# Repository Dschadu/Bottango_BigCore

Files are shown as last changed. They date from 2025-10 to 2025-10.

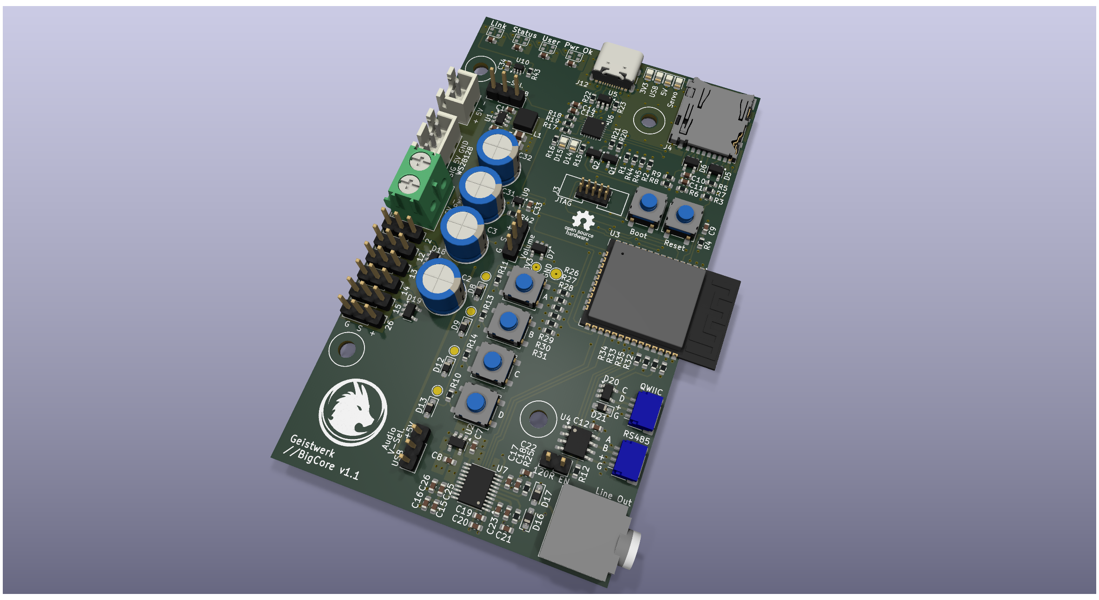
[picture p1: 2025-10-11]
PCB.png

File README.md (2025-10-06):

# ESP32 Bottango Control Board

This custom PCB is designed to serve as a **control and interface board** for projects using the [Bottango](https://www.bottango.com/) motion and animation control firmware.  
It provides robust connectivity, servo control, and expandability for animatronics or motion-based systems.

**Note**: This is a community project and not designed / maintained / officially supported by Bottango.

---

## Features

### Core
- **ESP32 microcontroller**
- **USB-C** connector for power and programming  
- **Selectable power source** for the ESP32:  
  - USB-C  
  - 5 V rail (from WS2812B)

---

### Inputs
- **4 user buttons** — freely assignable, e.g., for selecting animations  
- **1 stop button** — emergency or animation stop  
- **Potentiometer input** — for audio volume control  

---

### Outputs & Indicators
- **4 status LEDs** — indicate board or animation states  
- **Line-out audio output**  
- **6 servo connectors** (powered by dedicated power input)  
- **WS2812B output** — supports addressable RGB LEDs  
- **Selectable power source for audio section:**  
  - USB-C  
  - 5 V rail (from WS2812B)  
- **LED power indicators** for:  
  - 5 V  
  - 6 V  
  - USB-C  
  - 3.3 V  

---

### Connectivity
- **I²C (Qwiic-compatible connector)** — for sensor or peripheral expansion  
- **RS485 interface** — for robust long-distance serial communication  

---

## Power Overview

| Function | Voltage  | Source Options |
|---|---|---|
| ESP32 | 5 V | USB-C / 5 V line |
| Audio Output Circuit | 5 V | USB-C / 5 V line |
| WS2812B LEDs | 5 V | External supply |
| Servos | 6 V | External supply |

---

## Firmware Compatibility

This board is designed for use with **Bottango firmware**, providing smooth integration with Bottango Studio for real-time motion and animation control.  
Learn more at: [https://www.bottango.com/](https://www.bottango.com/)

**Note**: This is a community project and not designed / maintained / officially supported by Bottango.

---

## License

This hardware design is released under the  
**CERN Open Hardware Licence Version 2 – Weakly Reciprocal (CERN-OHL-W)**.  
© 2025 Martin Klein 

You are free to:
- Use, study, modify, and manufacture this design  
- Distribute modified versions under the same license  
- Incorporate this board into larger, closed-source systems, **as long as modifications to this board itself remain open-source**

For more information, see the [LICENSE](./LICENSE) file or the full text at
[CERN-OHL-W](https://gitlab.com/ohwr/project/cernohl/-/wikis/uploads/82b567f43ce515395f7ddbfbad7a8806/cern_ohl_w_v2.txt)

## Copyright Notice

Copyright Martin Klein 2025.

This source describes Open Hardware and is licensed under the CERN-OHLW v2

You may redistribute and modify this PCB and make products
using it under the terms of the CERN-OHL-W v2 (https:/cern.ch/cern-ohl).
This PCB is distributed WITHOUT ANY EXPRESS OR IMPLIED
WARRANTY, INCLUDING OF MERCHANTABILITY, SATISFACTORY QUALITY
AND FITNESS FOR A PARTICULAR PURPOSE. Please see the CERN-OHL-W v2
for applicable conditions.

Source location: https://github.com/Dschadu/Geistwerk-BigCore

As per CERN-OHL-W v2 section 4.1, should You produce hardware based on
these sources, You must maintain the Source Location visible in its
documentation.

## Acknowledgments

Special thanks to the Bottango team for providing an intuitive open platform for animatronic motion control.

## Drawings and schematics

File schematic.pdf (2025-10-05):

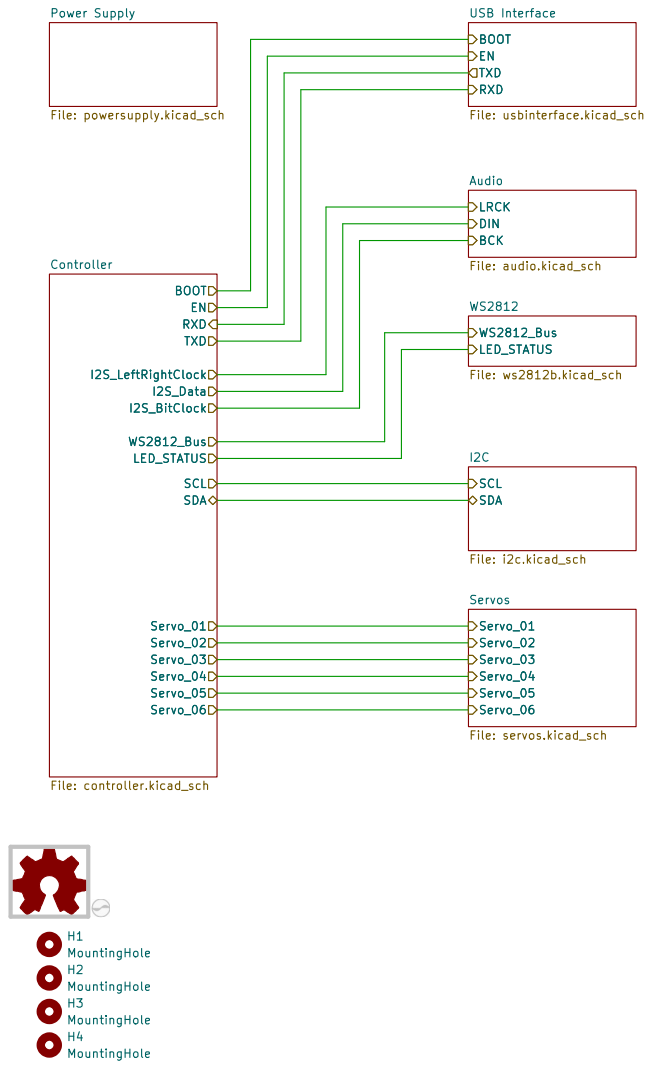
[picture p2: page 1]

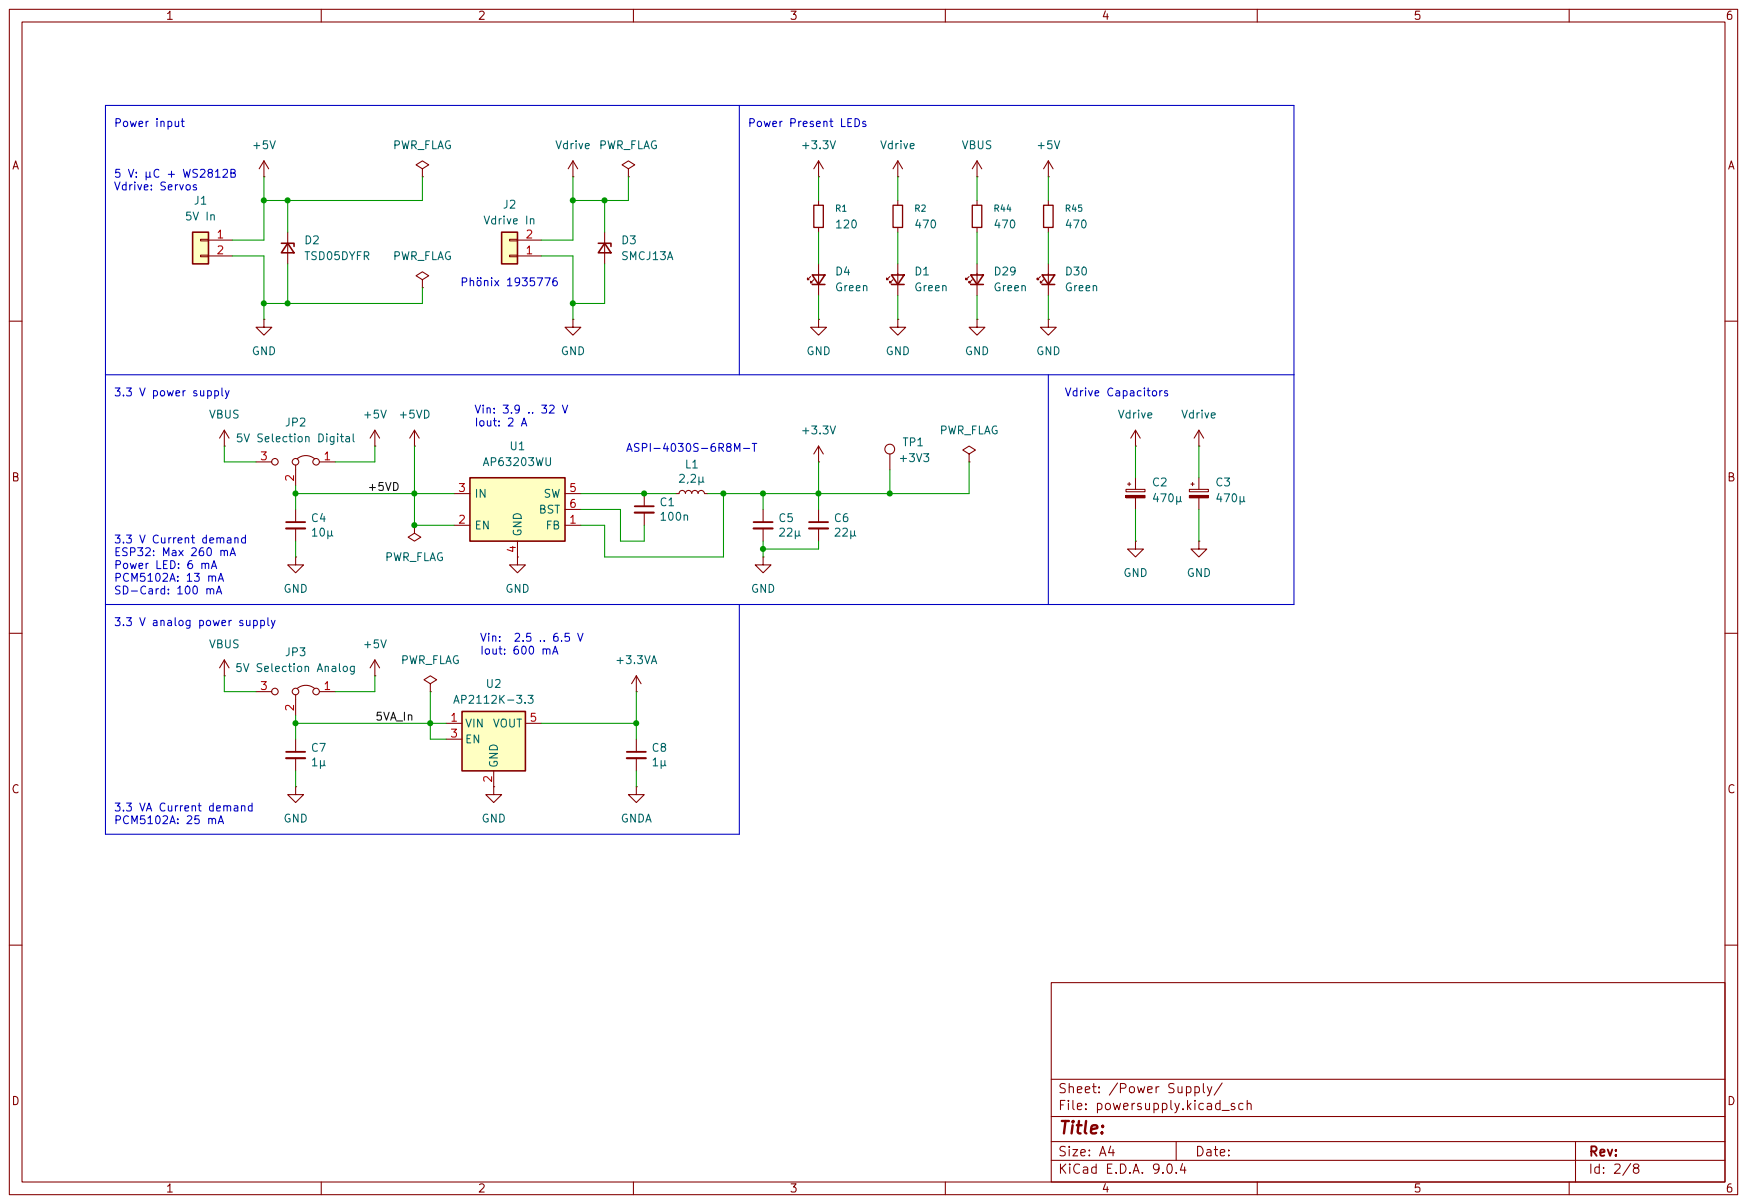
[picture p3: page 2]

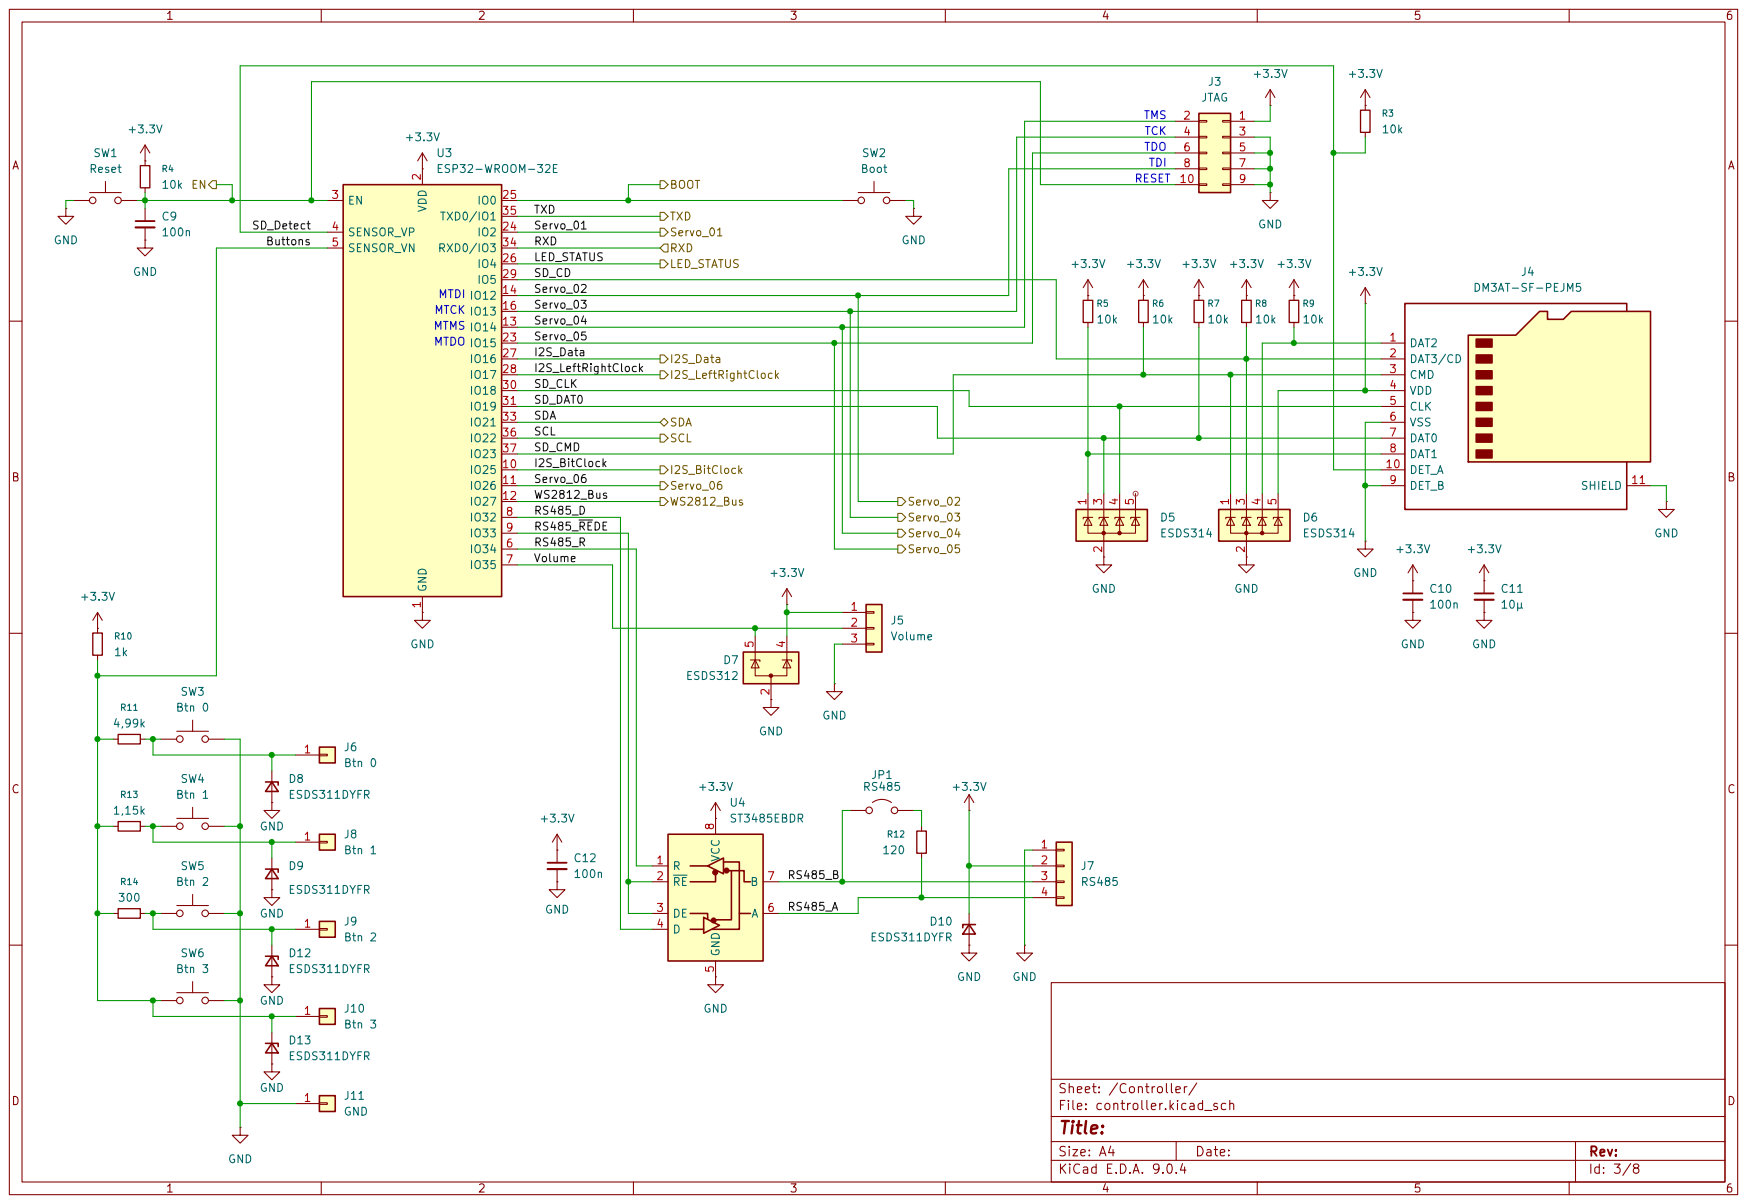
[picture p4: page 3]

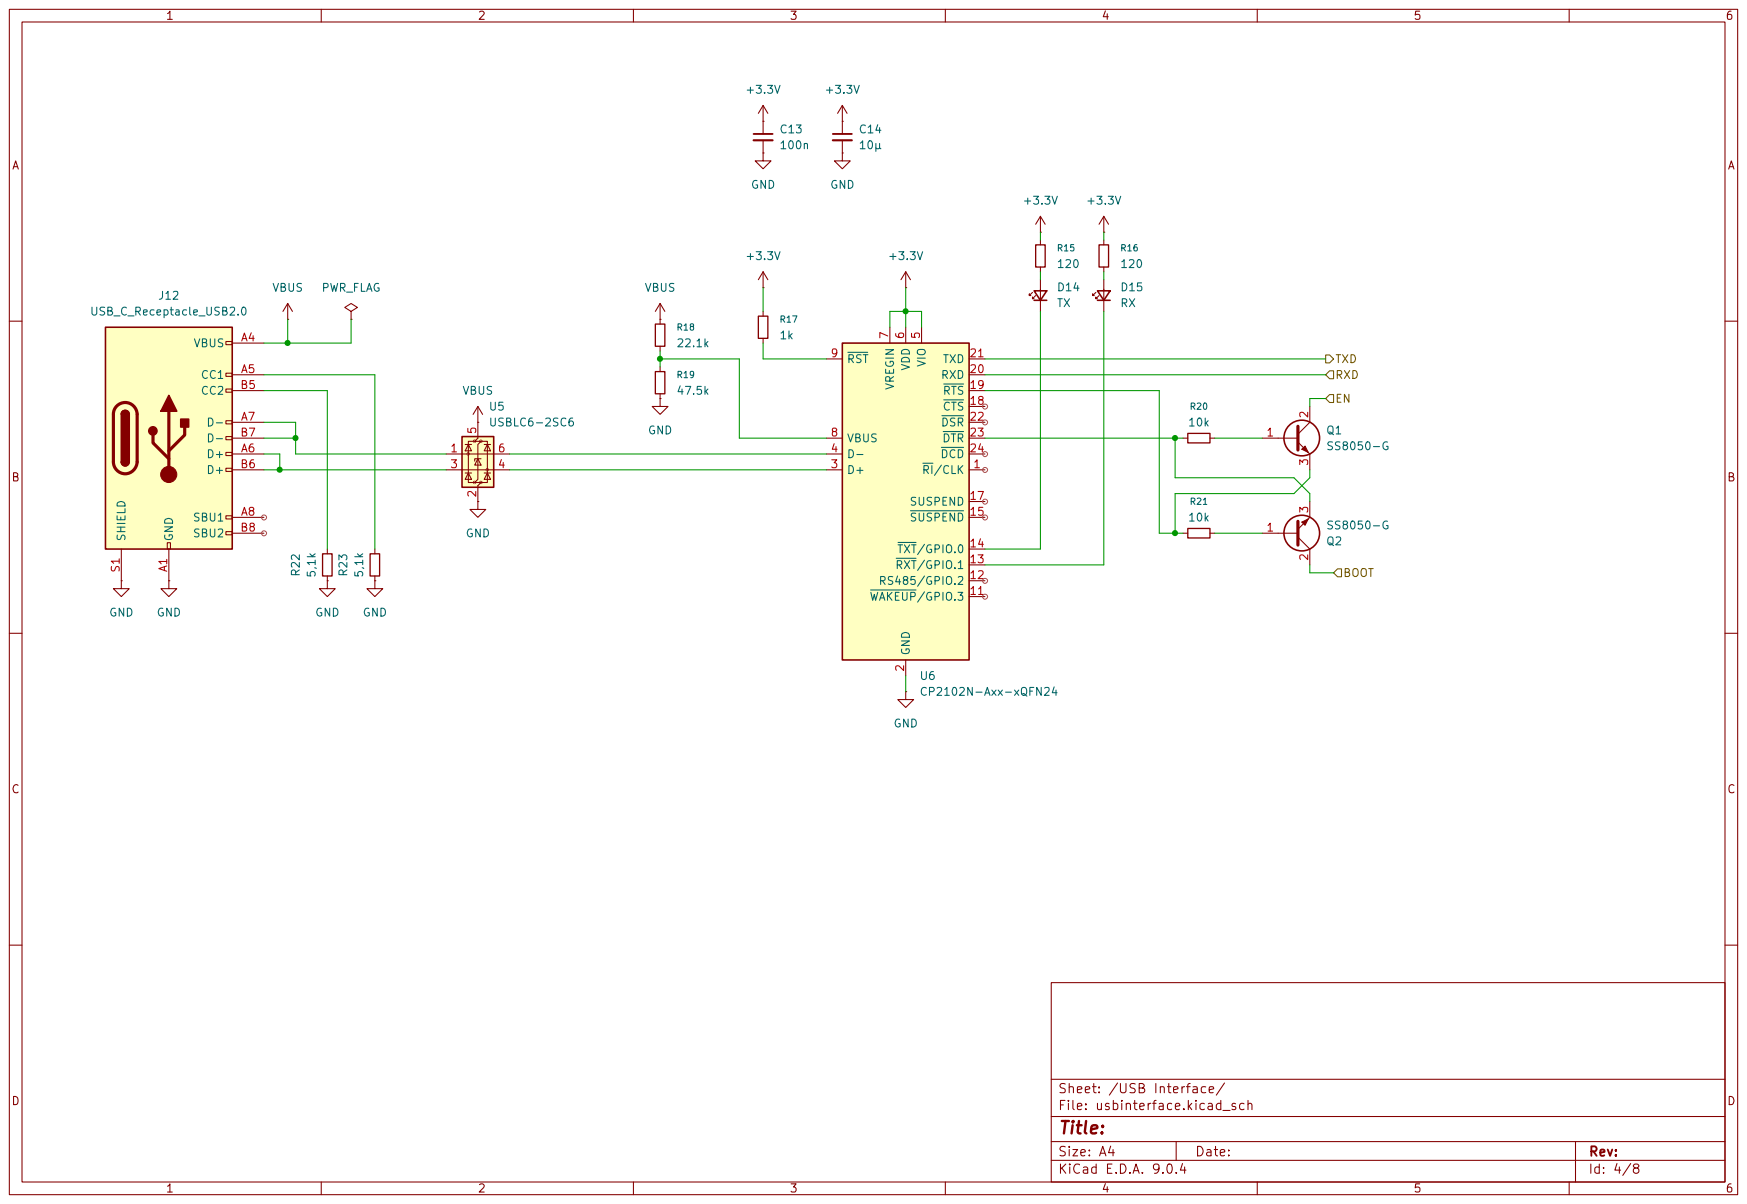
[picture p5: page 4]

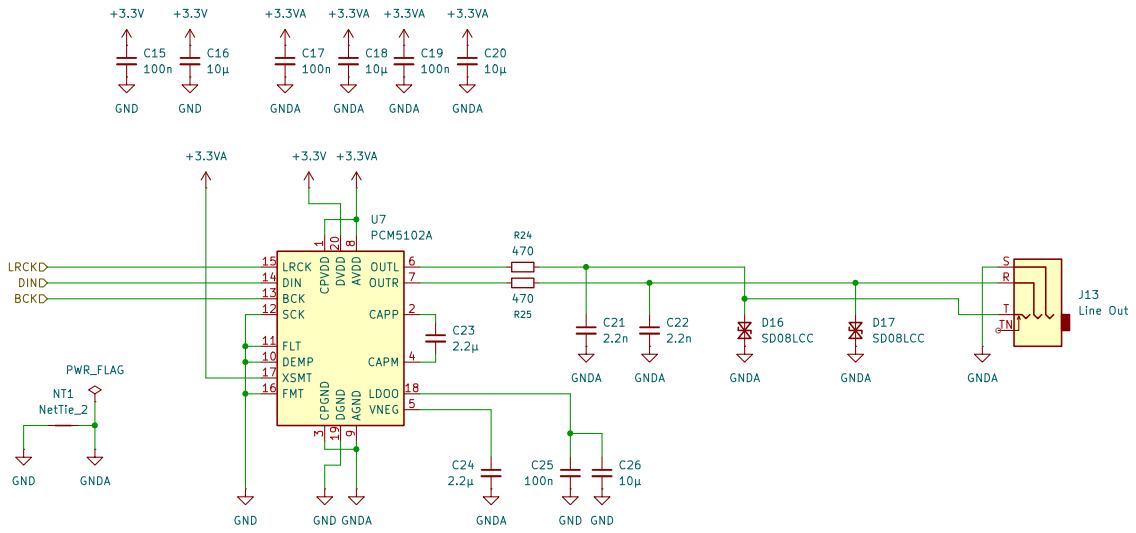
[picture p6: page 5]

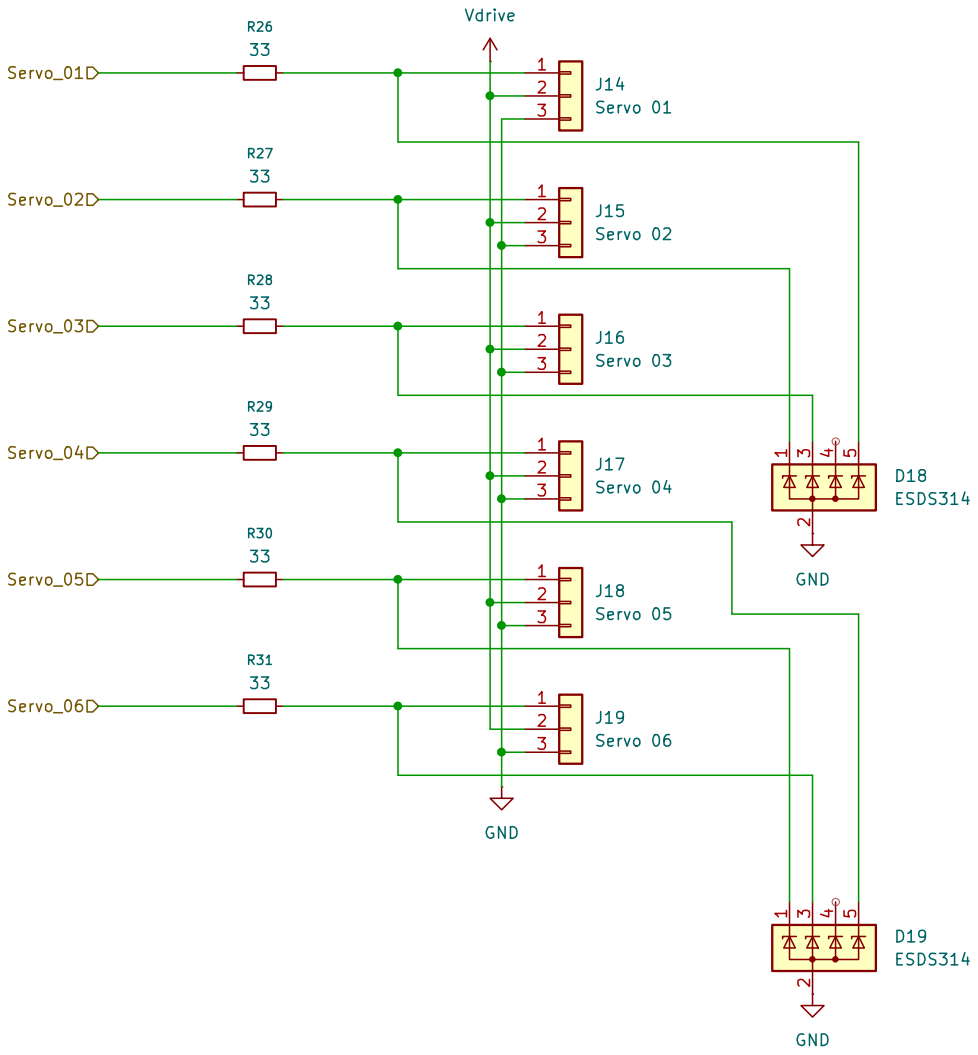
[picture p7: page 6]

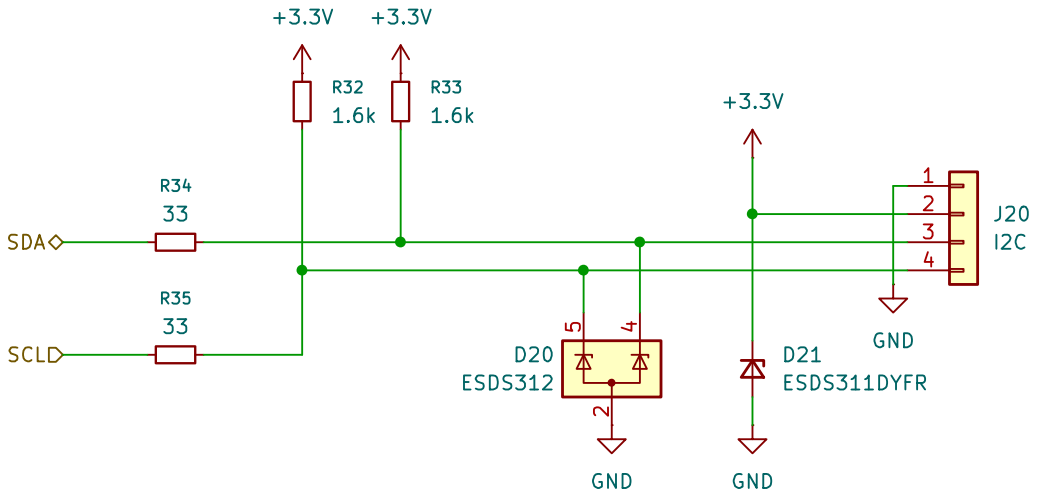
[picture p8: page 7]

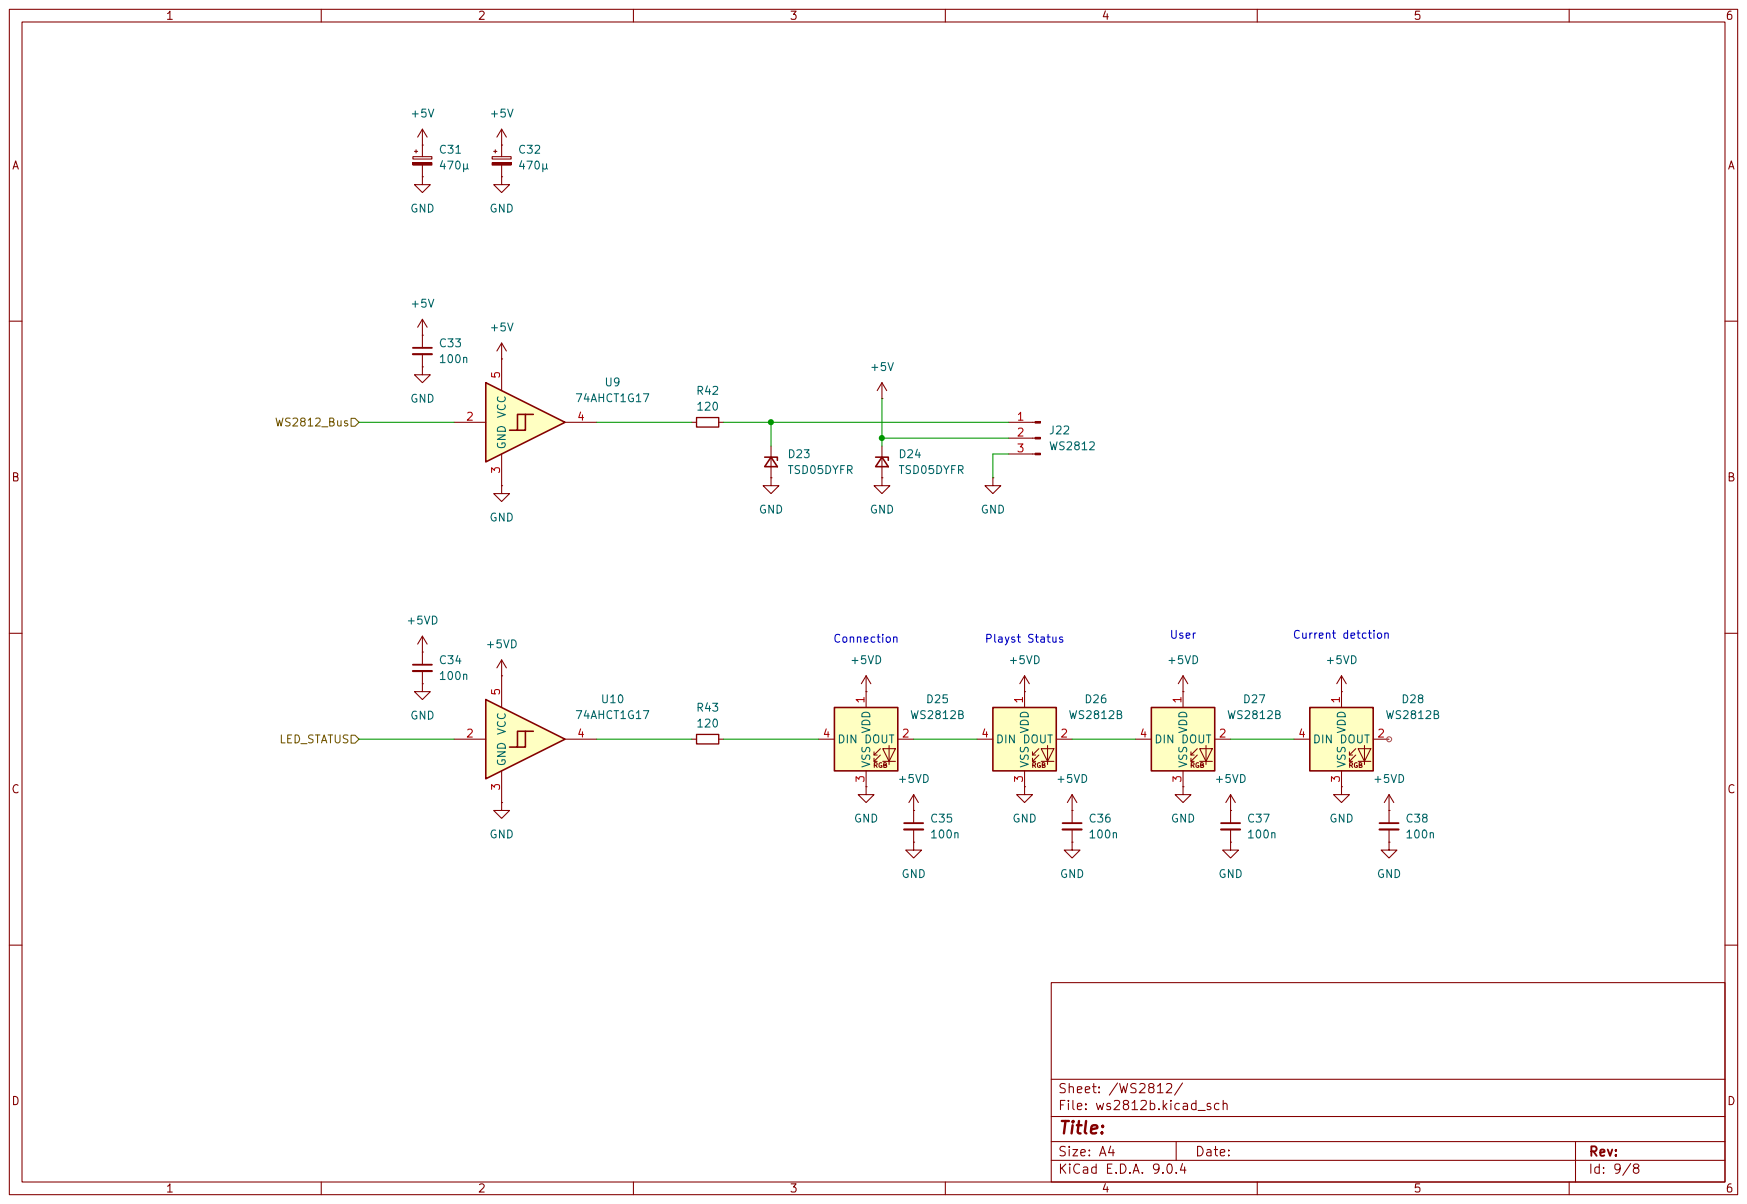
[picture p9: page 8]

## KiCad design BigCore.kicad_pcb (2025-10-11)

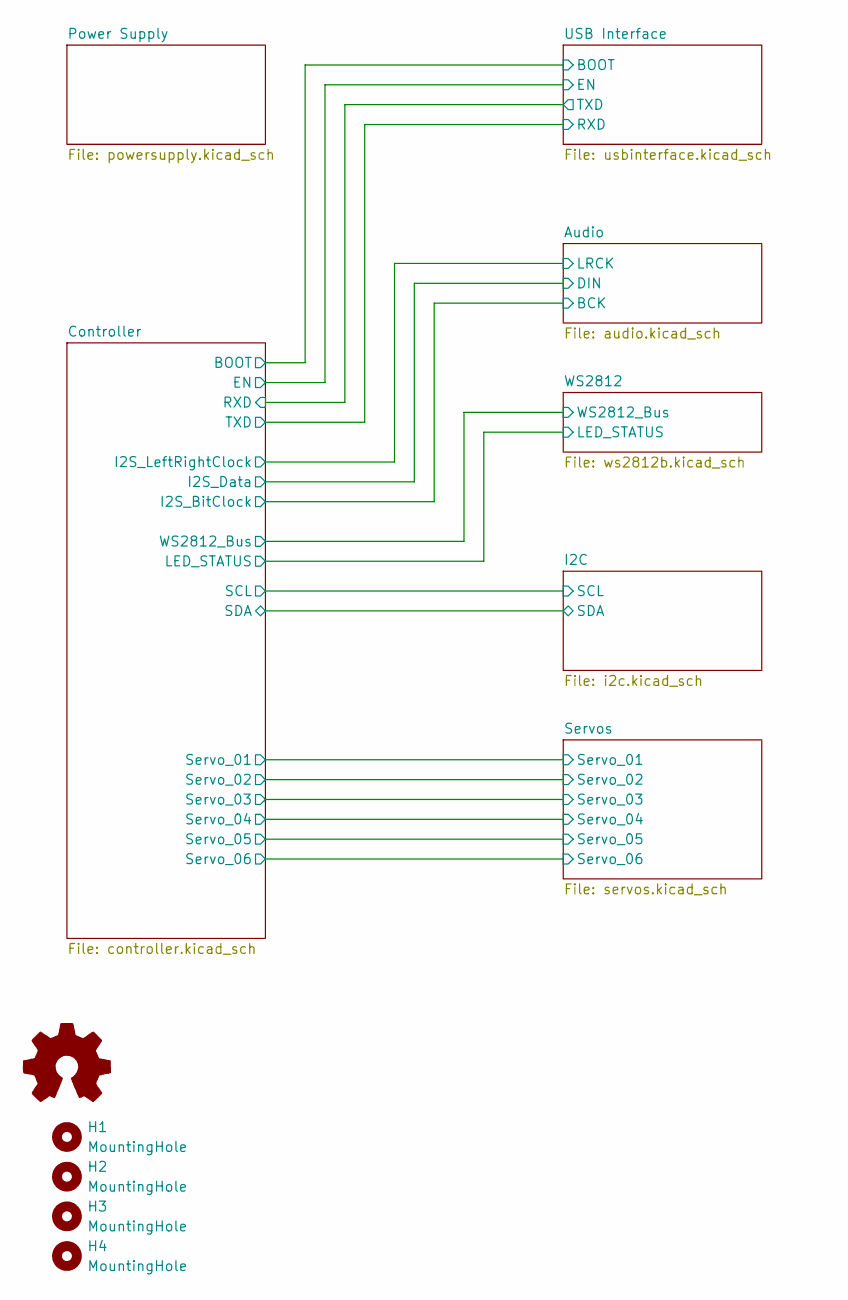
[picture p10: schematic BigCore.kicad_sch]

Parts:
H1, H2, H3, H4: MountingHole; MountingHole_3.2mm_M3
H5: Logo_Open_Hardware_Small; OSHW-Logo_5.7x6mm_SilkScreen

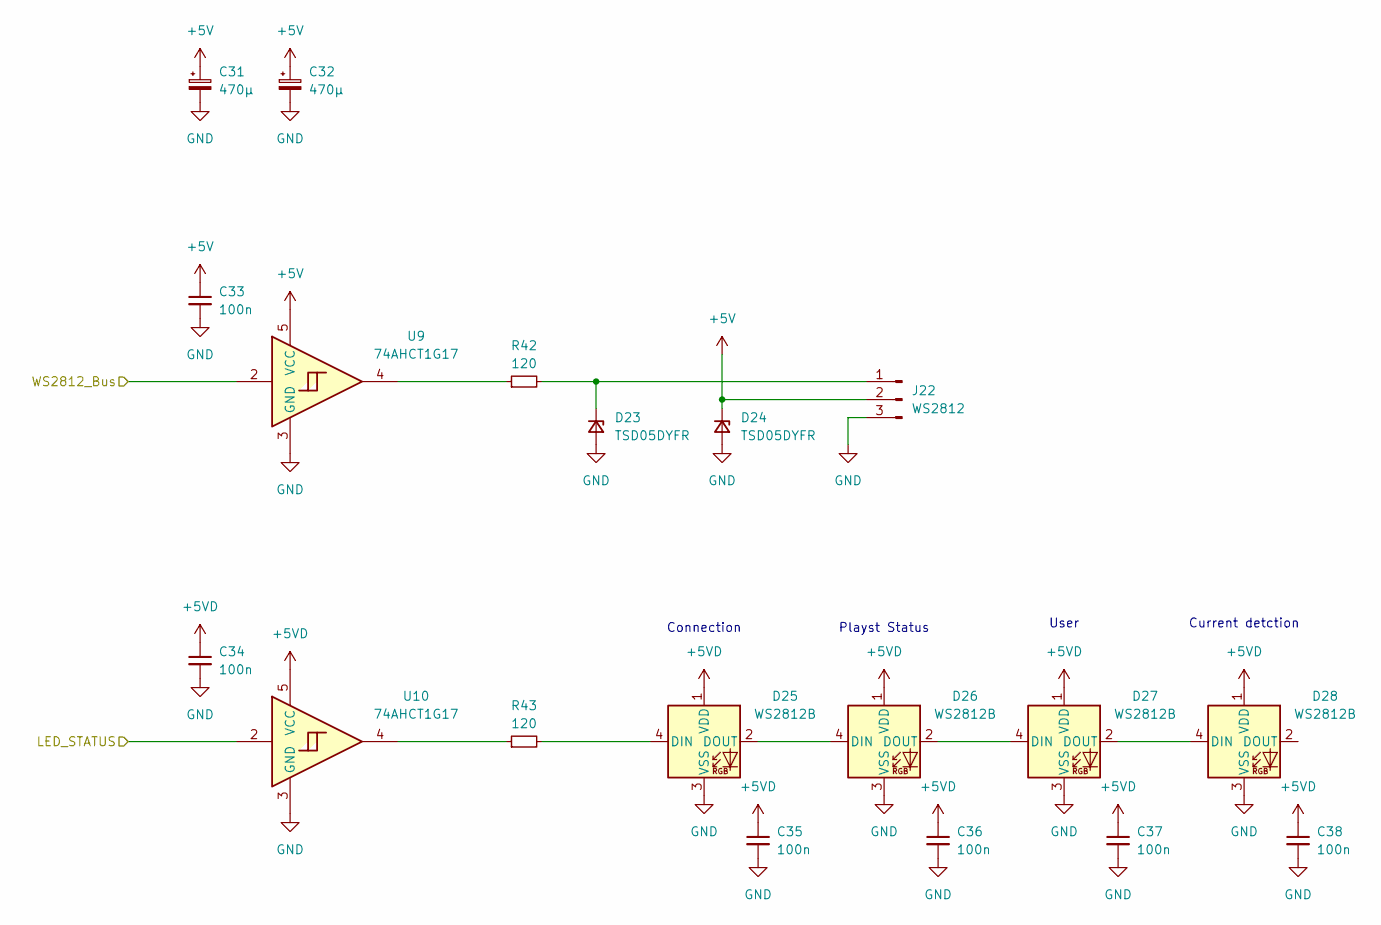
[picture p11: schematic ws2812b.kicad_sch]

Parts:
C31, C32: 470µ; CP_Radial_D8.0mm_P3.50mm
C33, C34, C35, C36, C37, C38: 100n; C_0603_1608Metric
D23, D24: TSD05DYFR; D_SOD-323_HandSoldering
D25, D26, D27, D28: WS2812B; LED_WS2812B-2020_PLCC4_2.0x2.0mm
J22: WS2812; JST_XH_B3B-XH-A_1x03_P2.50mm_Vertical
R42, R43: 120; R_0603_1608Metric
U9, U10: 74AHCT1G17; SOT-353_SC-70-5

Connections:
+5V: C31.1, C32.1, C33.1, D24.1 (K), J22.2, U9.5 (VCC); also elsewhere on the board
+5VD: C34.1, C35.1, C36.1, C37.1, C38.1, D25.1 (VDD), D26.1 (VDD), D27.1 (VDD), D28.1 (VDD), U10.5 (VCC); also elsewhere on the board
/Controller/LED_STATUS: U10.2; also elsewhere on the board
/Controller/WS2812_Bus: U9.2; also elsewhere on the board
GND: C31.2, C32.2, C33.2, C34.2, C35.2, C36.2, C37.2, C38.2, D23.2 (A), D24.2 (A), D25.3 (VSS), D26.3 (VSS), D27.3 (VSS), D28.3 (VSS), J22.3, U9.3 (GND), U10.3 (GND); also elsewhere on the board
unnamed: D23.1 (K), J22.1, R42.2
unnamed: D25.4 (DIN), R43.2
unnamed: D25.2 (DOUT), D26.4 (DIN)
unnamed: D26.2 (DOUT), D27.4 (DIN)
unnamed: D27.2 (DOUT), D28.4 (DIN)
unnamed: R42.1, U9.4
unnamed: R43.1, U10.4

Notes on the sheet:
Current detction
User
Connection
Playst Status

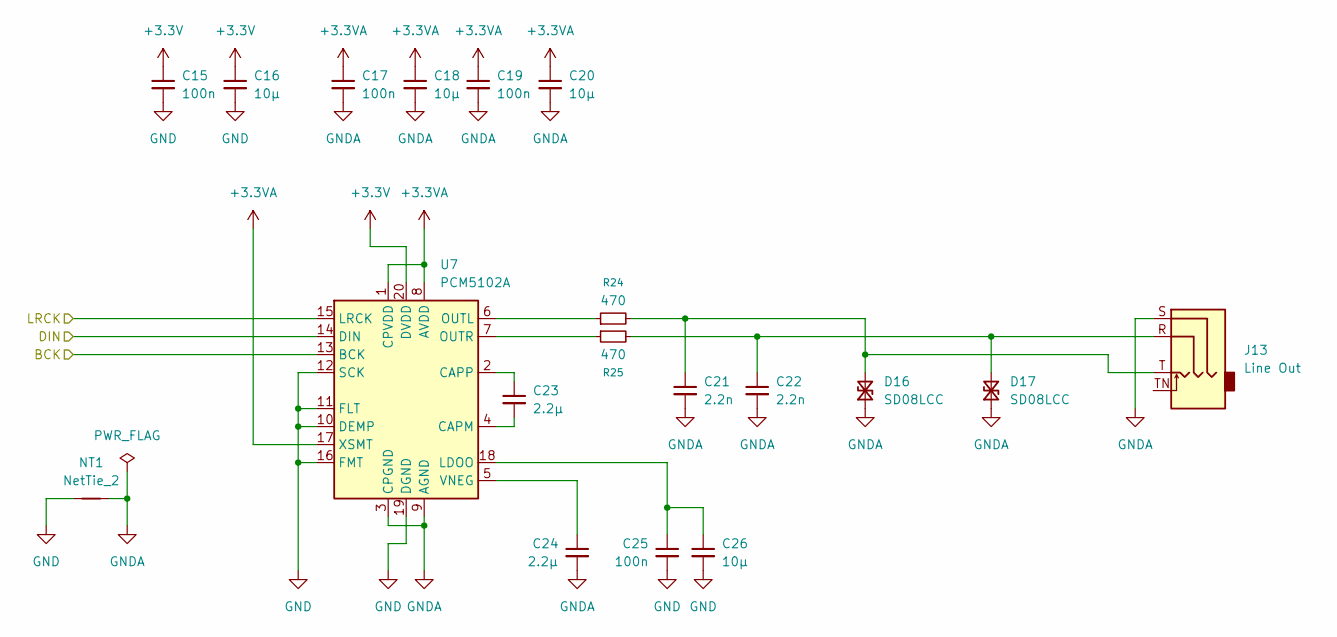
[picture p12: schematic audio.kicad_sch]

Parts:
C15, C17, C19, C25: 100n; C_0603_1608Metric
C16, C18, C20, C26: 10µ; C_0603_1608Metric
C21, C22: 2.2n; C_0603_1608Metric
C23, C24: 2.2µ; C_0603_1608Metric
D16, D17: SD08LCC; D_SOD-323_HandSoldering
J13: Line Out; Jack_3.5mm_CUI_SJ1-3524N_Horizontal
NT1: NetTie_2; NetTie-2_SMD_Pad0.5mm
R24, R25: 470; R_0603_1608Metric
U7: PCM5102A; TSSOP-20_4.4x6.5mm_P0.65mm

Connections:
+3.3V: C15.1, C16.1, U7.20 (DVDD); also elsewhere on the board
+3.3VA: C17.1, C18.1, C19.1, C20.1, U7.1 (CPVDD), U7.8 (AVDD), U7.17 (XSMT); also elsewhere on the board
/Controller/I2S_BitClock: U7.13 (BCK); also elsewhere on the board
/Controller/I2S_Data: U7.14 (DIN); also elsewhere on the board
/Controller/I2S_LeftRightClock: U7.15 (LRCK); also elsewhere on the board
GND: C15.2, C16.2, C25.2, C26.2, NT1.1, U7.10 (DEMP), U7.11 (FLT), U7.12 (SCK), U7.16 (FMT), U7.19 (DGND); also elsewhere on the board
GNDA: C17.2, C18.2, C19.2, C20.2, C21.2, C22.2, C24.2, D16.1 (A1), D17.1 (A1), J13.S, NT1.2, U7.3 (CPGND), U7.9 (AGND); also elsewhere on the board
unnamed: C21.1, D16.2 (A2), J13.T, R24.2
unnamed: C22.1, D17.2 (A2), J13.R, R25.2
unnamed: C23.2, U7.4 (CAPM)
unnamed: C23.1, U7.2 (CAPP)
unnamed: C25.1, C26.1, U7.18 (LDOO)
unnamed: R24.1, U7.6 (OUTL)
unnamed: R25.1, U7.7 (OUTR)
unnamed: C24.1, U7.5 (VNEG)

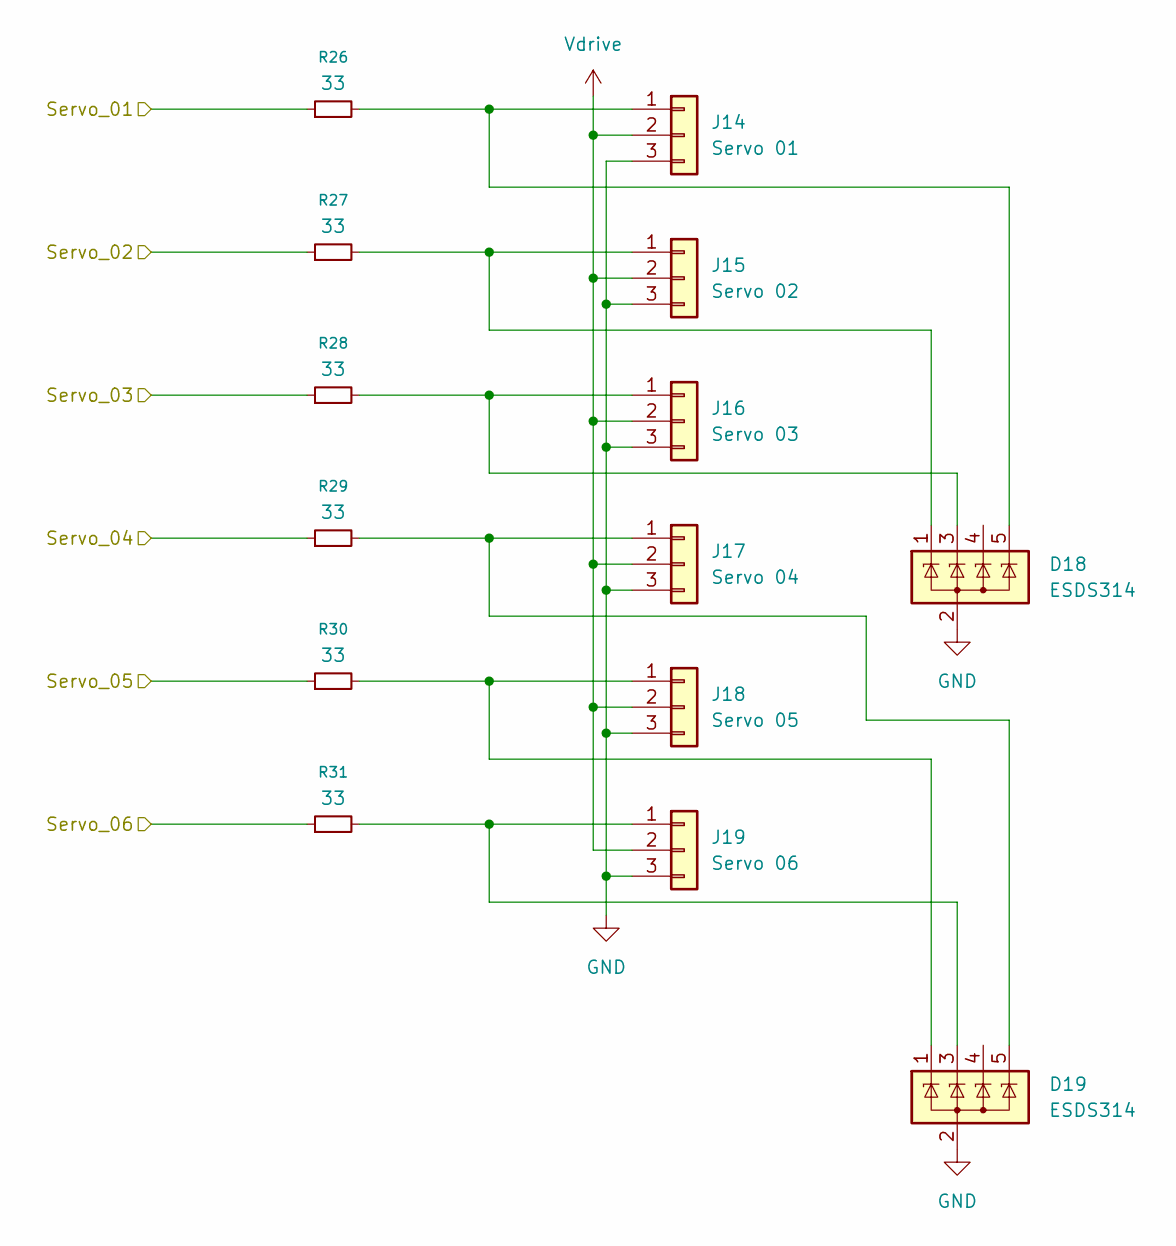
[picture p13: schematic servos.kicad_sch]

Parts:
D18, D19: ESDS314; SOT-23-5
J14: Servo 01; PinHeader_1x03_P2.54mm_Vertical
J15: Servo 02; PinHeader_1x03_P2.54mm_Vertical
J16: Servo 03; PinHeader_1x03_P2.54mm_Vertical
J17: Servo 04; PinHeader_1x03_P2.54mm_Vertical
J18: Servo 05; PinHeader_1x03_P2.54mm_Vertical
J19: Servo 06; PinHeader_1x03_P2.54mm_Vertical
R26, R27, R28, R29, R30, R31: 33; R_0603_1608Metric

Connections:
/Controller/Servo_01: R26.1; also elsewhere on the board
/Controller/Servo_02: R27.1; also elsewhere on the board
/Controller/Servo_03: R28.1; also elsewhere on the board
/Controller/Servo_04: R29.1; also elsewhere on the board
/Controller/Servo_05: R30.1; also elsewhere on the board
/Controller/Servo_06: R31.1; also elsewhere on the board
GND: D18.2 (A), D19.2 (A), J14.3, J15.3, J16.3, J17.3, J18.3, J19.3; also elsewhere on the board
unnamed: D18.5 (K), J14.1, R26.2
unnamed: D18.1 (K), J15.1, R27.2
unnamed: D18.3 (K), J16.1, R28.2
unnamed: D19.5 (K), J17.1, R29.2
unnamed: D19.1 (K), J18.1, R30.2
unnamed: D19.3 (K), J19.1, R31.2
Vdrive: J14.2, J15.2, J16.2, J17.2, J18.2, J19.2; also elsewhere on the board

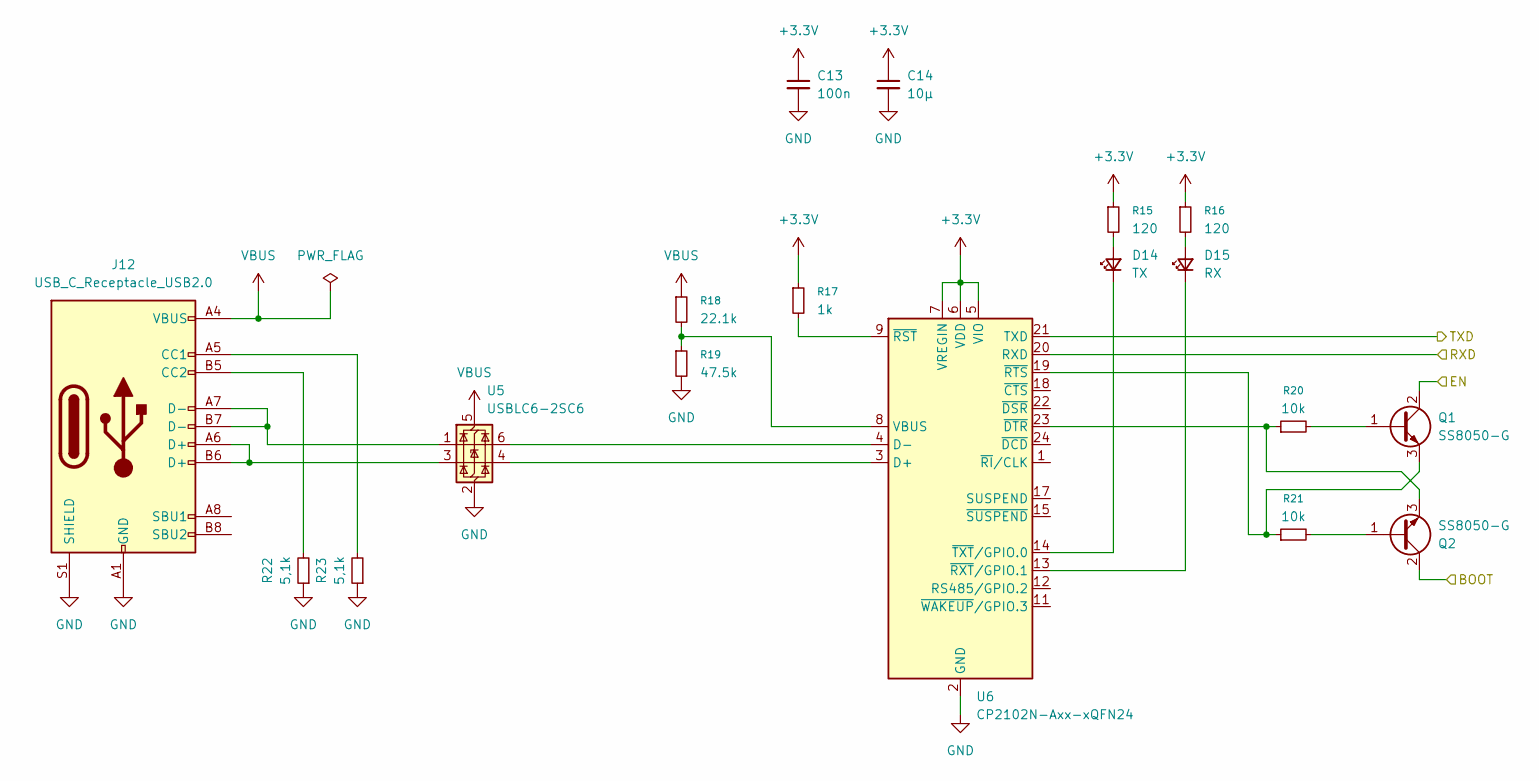
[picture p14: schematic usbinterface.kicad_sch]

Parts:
C13: 100n; C_0603_1608Metric
C14: 10µ; C_0603_1608Metric
D14: TX; LED_0805_2012Metric
D15: RX; LED_0805_2012Metric
J12: USB_C_Receptacle_USB2.0; USB_C_Receptacle_GCT_USB4105-xx-A_16P_TopMnt_Horizontal
Q1, Q2: SS8050-G; SOT-23-3
R15, R16: 120; R_0603_1608Metric
R17: 1k; R_0603_1608Metric
R18: 22.1k; R_0603_1608Metric
R19: 47.5k; R_0603_1608Metric
R20, R21: 10k; R_0603_1608Metric
R22, R23: 5,1k; R_0603_1608Metric
U5: USBLC6-2SC6; SOT-23-6
U6: CP2102N-Axx-xQFN24; QFN-24-1EP_4x4mm_P0.5mm_EP2.6x2.6mm

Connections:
+3.3V: C13.1, C14.1, R15.1, R16.1, R17.1, U6.5 (VIO), U6.6 (VDD), U6.7 (VREGIN); also elsewhere on the board
/Controller/BOOT: Q2.2 (C); also elsewhere on the board
/Controller/EN: Q1.2 (C); also elsewhere on the board
/Controller/RXD: U6.21 (TXD); also elsewhere on the board
/Controller/TXD: U6.20 (RXD); also elsewhere on the board
GND: C13.2, C14.2, J12.A1 (GND), J12.A12 (GND), J12.B1 (GND), J12.B12 (GND), J12.S1 (SHIELD), R19.2, R22.1, R23.1, U5.2 (GND), U6.2 (GND), U6.25 (GND); also elsewhere on the board
unnamed: D14.2 (A), R15.2
unnamed: D14.1 (K), U6.14 (~TXT/GPIO.0)
unnamed: D15.2 (A), R16.2
unnamed: D15.1 (K), U6.13 (~RXT/GPIO.1)
unnamed: J12.A5 (CC1), R23.2
unnamed: J12.B5 (CC2), R22.2
unnamed: J12.A6 (D+), J12.B6 (D+), U5.3 (I/O2)
unnamed: J12.A7 (D-), J12.B7 (D-), U5.1 (I/O1)
unnamed: Q1.1 (B), R20.2
unnamed: Q1.3 (E), R21.1, U6.19 (~RTS)
unnamed: Q2.1 (B), R21.2
unnamed: Q2.3 (E), R20.1, U6.23 (~DTR)
unnamed: U5.4 (I/O2), U6.3 (D+)
unnamed: U5.6 (I/O1), U6.4 (D-)
unnamed: R18.2, R19.1, U6.8 (VBUS)
unnamed: R17.2, U6.9 (~RST)
VBUS: J12.A4 (VBUS), J12.A9 (VBUS), J12.B4 (VBUS), J12.B9 (VBUS), R18.1, U5.5 (VBUS); also elsewhere on the board

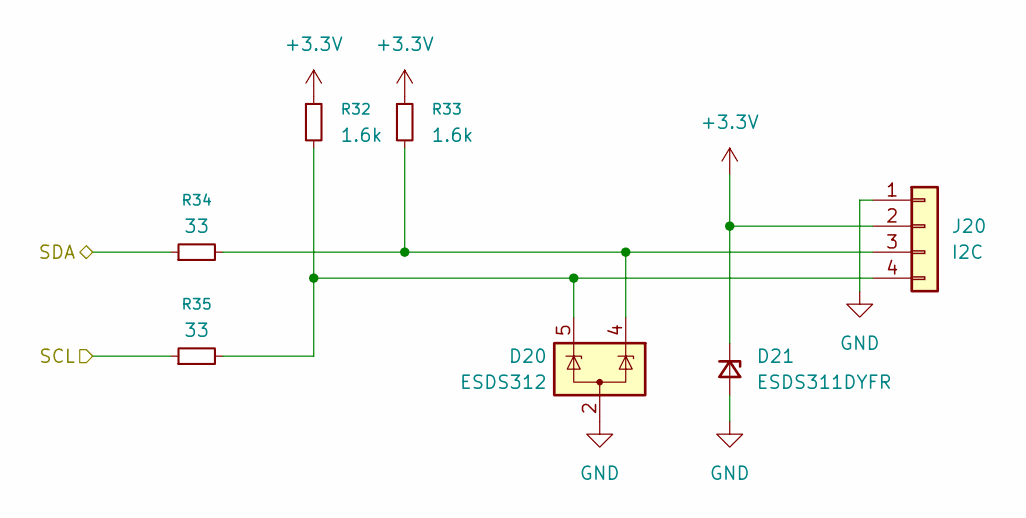
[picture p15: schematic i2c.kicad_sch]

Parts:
D20: ESDS312; SOT-23-5
D21: ESDS311DYFR; D_SOD-323_HandSoldering
J20: I2C; JST_SH_SM04B-SRSS-TB_1x04-1MP_P1.00mm_Horizontal
R32, R33: 1.6k; R_0603_1608Metric
R34, R35: 33; R_0603_1608Metric

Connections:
+3.3V: D21.1 (K), J20.2, R32.1, R33.1; also elsewhere on the board
/Controller/SCL: R35.1; also elsewhere on the board
/Controller/SDA: R34.1; also elsewhere on the board
GND: D20.2 (A), D21.2 (A), J20.1; also elsewhere on the board
unnamed: D20.4 (K), J20.3, R33.2, R34.2
unnamed: D20.5 (K), J20.4, R32.2, R35.2

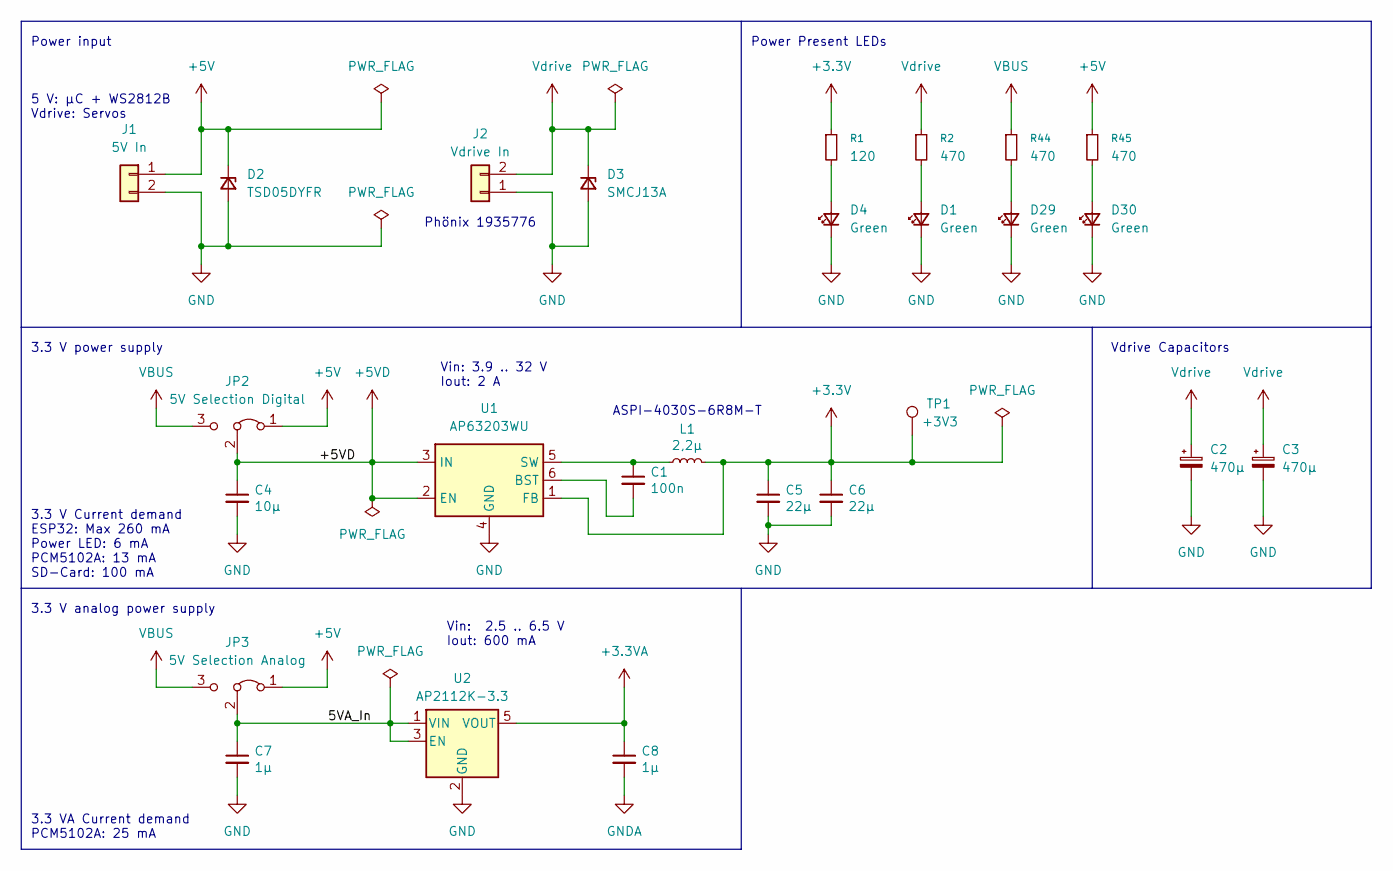
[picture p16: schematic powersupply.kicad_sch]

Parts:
C1: 100n; C_0603_1608Metric
C2, C3: 470µ; CP_Radial_D8.0mm_P3.50mm
C4: 10µ; C_0603_1608Metric
C5, C6: 22µ; C_0805_2012Metric
C7, C8: 1µ; C_0603_1608Metric
D1, D4, D29, D30: Green; LED_0805_2012Metric
D2: TSD05DYFR; D_SOD-323_HandSoldering
D3: SMCJ13A; D_SMA_Handsoldering
J1: 5V In; JST_XH_B2B-XH-A_1x02_P2.50mm_Vertical
J2: Vdrive In; TerminalBlock_Phoenix_PT-1,5-2-5.0-H_1x02_P5.00mm_Horizontal
JP2: 5V Selection Digital; PinHeader_1x03_P2.54mm_Vertical
JP3: 5V Selection Analog; PinHeader_1x03_P2.54mm_Vertical
L1: 2,2µ; L_APV_ANR4020
R1: 120; R_0603_1608Metric
R2, R44, R45: 470; R_0603_1608Metric
TP1: +3V3; TestPoint_Pad_D1.5mm
U1: AP63203WU; TSOT-23-6
U2: AP2112K-3.3; SOT-23-5

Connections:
+3.3V: C5.1, C6.1, L1.2, R1.1, TP1.1, U1.1 (FB); also elsewhere on the board
+3.3VA: C8.1, U2.5 (VOUT); also elsewhere on the board
+5V: D2.1 (K), J1.1, JP2.1 (A), JP3.1 (A), R45.1; also elsewhere on the board
+5VD: C4.1, JP2.2 (C), U1.2 (EN), U1.3 (IN); also elsewhere on the board
/Power Supply/5VA_In: C7.1, JP3.2 (C), U2.1 (VIN), U2.3 (EN)
GND: C2.2, C3.2, C4.2, C5.2, C6.2, C7.2, D1.1 (K), D2.2 (A), D3.2 (A), D4.1 (K), D29.1 (K), D30.1 (K), J1.2, J2.1, U1.4 (GND), U2.2 (GND); also elsewhere on the board
GNDA: C8.2; also elsewhere on the board
unnamed: D1.2 (A), R2.2
unnamed: D4.2 (A), R1.2
unnamed: D29.2 (A), R44.2
unnamed: D30.2 (A), R45.2
unnamed: C1.2, U1.6 (BST)
unnamed: C1.1, L1.1, U1.5 (SW)
VBUS: JP2.3 (B), JP3.3 (B), R44.1; also elsewhere on the board
Vdrive: C2.1, C3.1, D3.1 (K), J2.2, R2.1; also elsewhere on the board

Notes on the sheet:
Power Present LEDs
Vdrive Capacitors
Phönix 1935776
Power input
Vin: 2.5 .. 6.5 V Iout: 600 mA
ASPI-4030S-6R8M-T
3.3 V Current demand ESP32: Max 260 mA Power LED: 6 mA PCM5102A: 13 mA SD-Card: 100 mA
5 V: µC + WS2812B Vdrive: Servos
3.3 V power supply
Vin: 3.9 .. 32 V Iout: 2 A
3.3 VA Current demand PCM5102A: 25 mA
3.3 V analog power supply

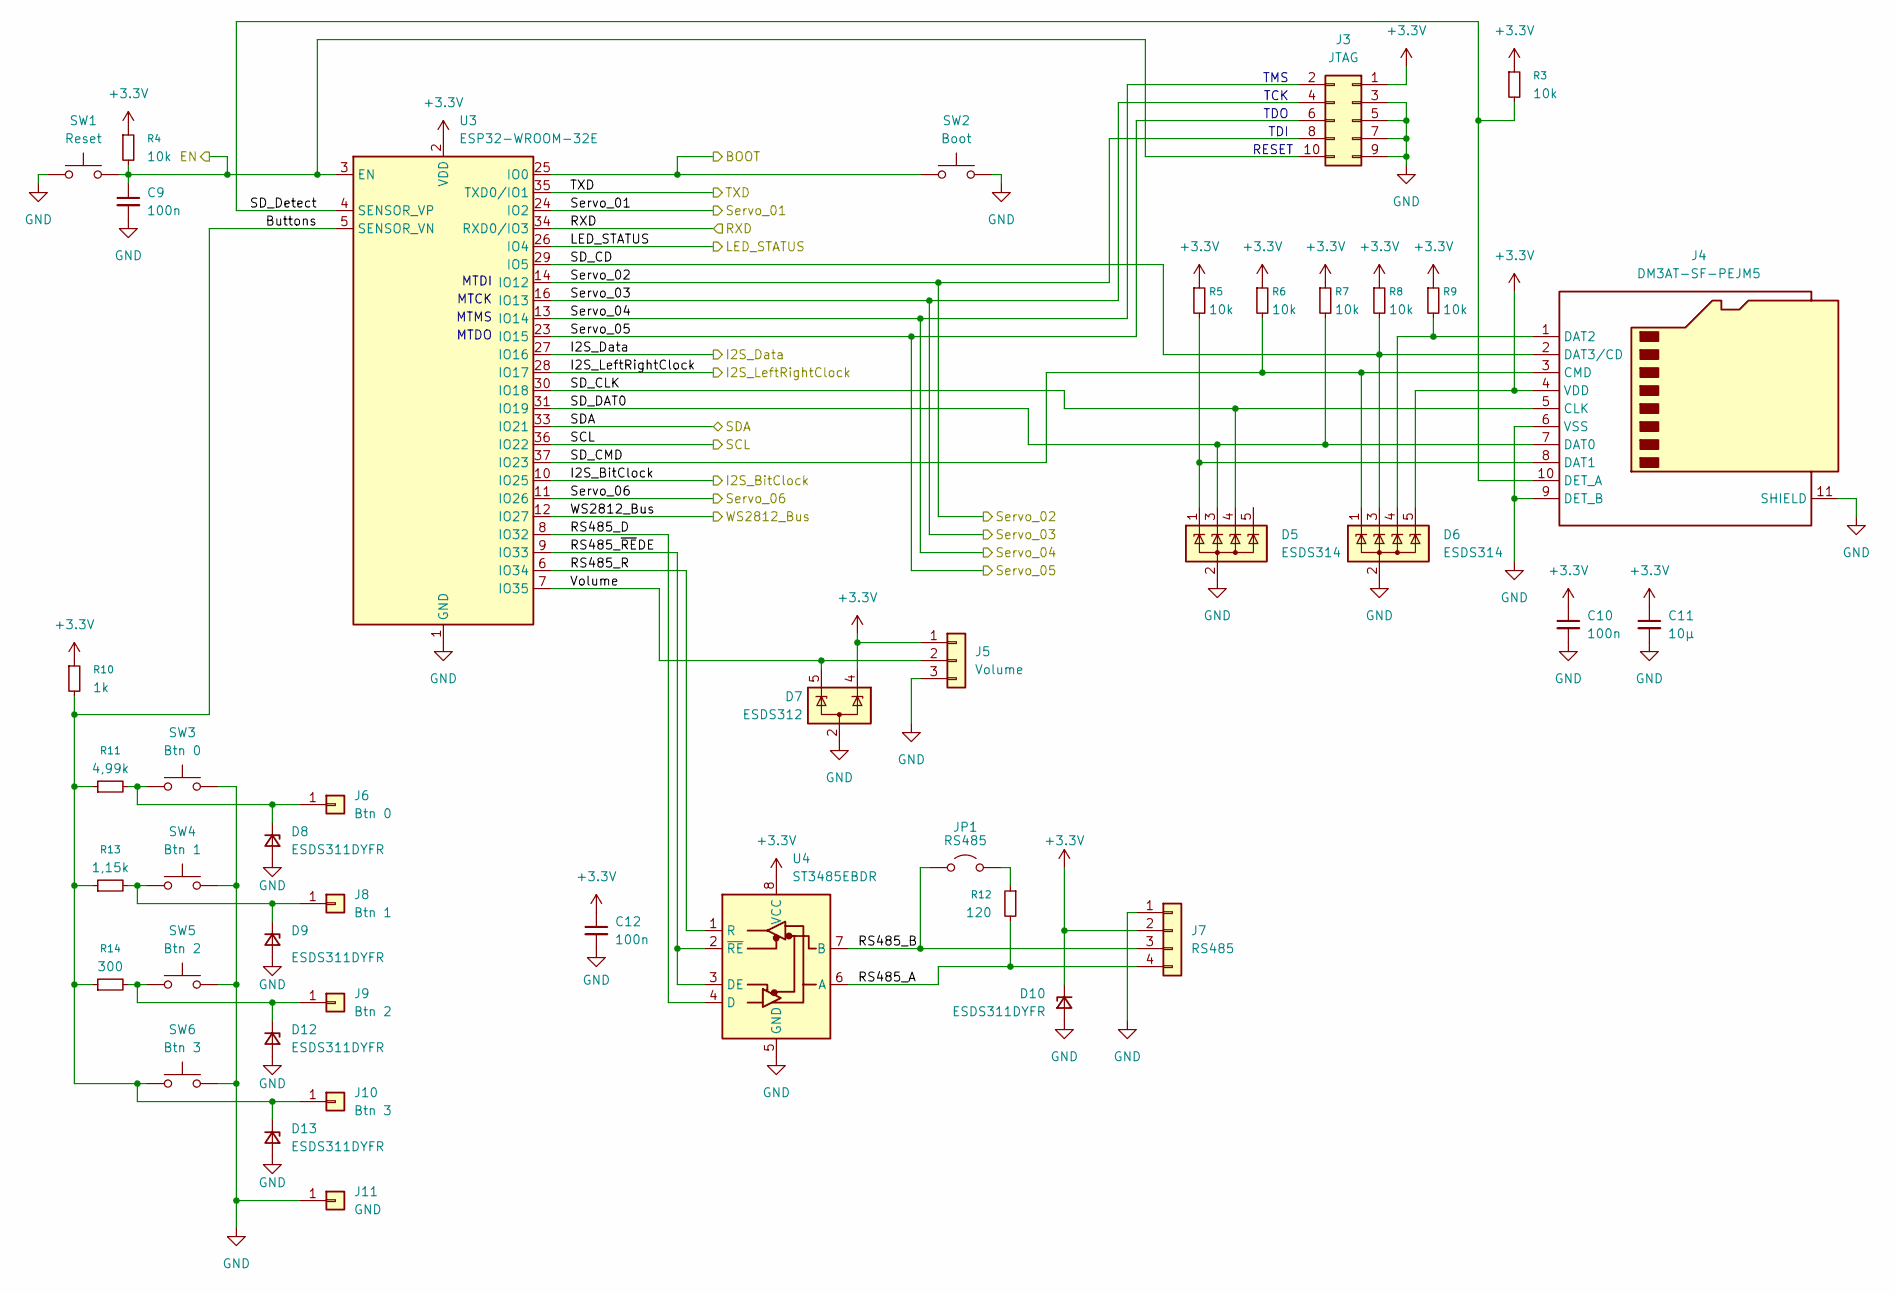
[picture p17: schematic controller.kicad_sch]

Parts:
C9, C10, C12: 100n; C_0603_1608Metric
C11: 10µ; C_0603_1608Metric
D5, D6: ESDS314; SOT-23-5
D7: ESDS312; SOT-23-5
D8, D9, D10, D12, D13: ESDS311DYFR; D_SOD-323_HandSoldering
J3: JTAG; PinHeader_2x05_P1.27mm_Vertical
J4: DM3AT-SF-PEJM5; microSD_HC_Hirose_DM3AT-SF-PEJM5
J5: Volume; PinHeader_1x03_P2.54mm_Vertical
J6: Btn 0; TestPoint_Pad_D1.5mm
J7: RS485; JST_SH_SM04B-SRSS-TB_1x04-1MP_P1.00mm_Horizontal
J8: Btn 1; TestPoint_Pad_D1.5mm
J9: Btn 2; TestPoint_Pad_D1.5mm
J10: Btn 3; TestPoint_Pad_D1.5mm
J11: GND; TestPoint_Pad_D2.0mm
JP1: RS485; PinHeader_1x02_P2.54mm_Vertical
R3, R4, R5, R6, R7, R8, R9: 10k; R_0603_1608Metric
R10: 1k; R_0603_1608Metric
R11: 4,99k; R_0603_1608Metric
R12: 120; R_0603_1608Metric
R13: 1,15k; R_0603_1608Metric
R14: 300; R_0603_1608Metric
SW1: Reset; SW_Push_1P1T_NO_CK_KSC7xxJ
SW2: Boot; SW_Push_1P1T_NO_CK_KSC7xxJ
SW3: Btn 0; SW_Push_1P1T_NO_CK_KSC7xxJ
SW4: Btn 1; SW_Push_1P1T_NO_CK_KSC7xxJ
SW5: Btn 2; SW_Push_1P1T_NO_CK_KSC7xxJ
SW6: Btn 3; SW_Push_1P1T_NO_CK_KSC7xxJ
U3: ESP32-WROOM-32E
U4: ST3485EBDR; SOIC-8_3.9x4.9mm_P1.27mm

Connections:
+3.3V: C10.1, C11.1, C12.1, D6.5 (K), D7.4 (K), D10.1 (K), J3.1, J4.4 (VDD), J5.1, J7.2, R3.1, R4.1, R5.1, R6.1, R7.1, R8.1, R9.1, R10.1, U3.2 (VDD), U4.8 (VCC); also elsewhere on the board
/Controller/BOOT: SW2.1, U3.25 (IO0); also elsewhere on the board
/Controller/Buttons: D13.1 (K), J10.1, R10.2, R11.1, R13.1, R14.1, SW6.2, U3.5 (SENSOR_VN)
/Controller/EN: C9.1, J3.10, R4.2, SW1.1, U3.3 (EN); also elsewhere on the board
/Controller/I2S_BitClock: U3.10 (IO25); also elsewhere on the board
/Controller/I2S_Data: U3.27 (IO16); also elsewhere on the board
/Controller/I2S_LeftRightClock: U3.28 (IO17); also elsewhere on the board
/Controller/LED_STATUS: U3.26 (IO4); also elsewhere on the board
/Controller/RS485_A: J7.4, R12.2, U4.6 (A)
/Controller/RS485_B: J7.3, JP1.1 (A), U4.7 (B)
/Controller/RS485_D: U3.8 (IO32), U4.4 (D)
/Controller/RS485_R: U3.6 (IO34), U4.1 (R)
/Controller/RS485_~REDE: U3.9 (IO33), U4.2 (~RE), U4.3 (DE)
/Controller/RXD: U3.34 (RXD0/IO3); also elsewhere on the board
/Controller/SCL: U3.36 (IO22); also elsewhere on the board
/Controller/SDA: U3.33 (IO21); also elsewhere on the board
/Controller/SD_CD: D6.3 (K), J4.2 (DAT3/CD), R8.2, U3.29 (IO5)
/Controller/SD_CLK: D5.4 (K), J4.5 (CLK), U3.30 (IO18)
/Controller/SD_CMD: D6.1 (K), J4.3 (CMD), R6.2, U3.37 (IO23)
/Controller/SD_DAT0: D5.3 (K), J4.7 (DAT0), R7.2, U3.31 (IO19)
/Controller/SD_Detect: J4.10 (DET_A), R3.2, U3.4 (SENSOR_VP)
/Controller/Servo_01: U3.24 (IO2); also elsewhere on the board
/Controller/Servo_02: J3.8, U3.14 (IO12); also elsewhere on the board
/Controller/Servo_03: J3.4, U3.16 (IO13); also elsewhere on the board
/Controller/Servo_04: J3.2, U3.13 (IO14); also elsewhere on the board
/Controller/Servo_05: J3.6, U3.23 (IO15); also elsewhere on the board
/Controller/Servo_06: U3.11 (IO26); also elsewhere on the board
/Controller/TXD: U3.35 (TXD0/IO1); also elsewhere on the board
/Controller/Volume: D7.5 (K), J5.2, U3.7 (IO35)
/Controller/WS2812_Bus: U3.12 (IO27); also elsewhere on the board
GND: C9.2, C10.2, C11.2, C12.2, D5.2 (A), D6.2 (A), D7.2 (A), D8.2 (A), D9.2 (A), D10.2 (A), D12.2 (A), D13.2 (A), J3.3, J3.5, J3.7, J3.9, J4.6 (VSS), J4.9 (DET_B), J4.11 (SHIELD), J5.3, J7.1, J11.1, SW1.2, SW2.2, SW3.1, SW4.1, SW5.1, SW6.1, U3.1 (GND), U3.15 (GND), U3.38 (GND), U3.39 (GND), U4.5 (GND); also elsewhere on the board
unnamed: D8.1 (K), J6.1, R11.2, SW3.2
unnamed: D9.1 (K), J8.1, R13.2, SW4.2
unnamed: D12.1 (K), J9.1, R14.2, SW5.2
unnamed: D5.1 (K), J4.8 (DAT1), R5.2
unnamed: D6.4 (K), J4.1 (DAT2), R9.2
unnamed: JP1.2 (B), R12.1

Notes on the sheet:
MTDO
MTCK
RESET
TMS
MTDI
MTMS
TCK
TDO
TDI

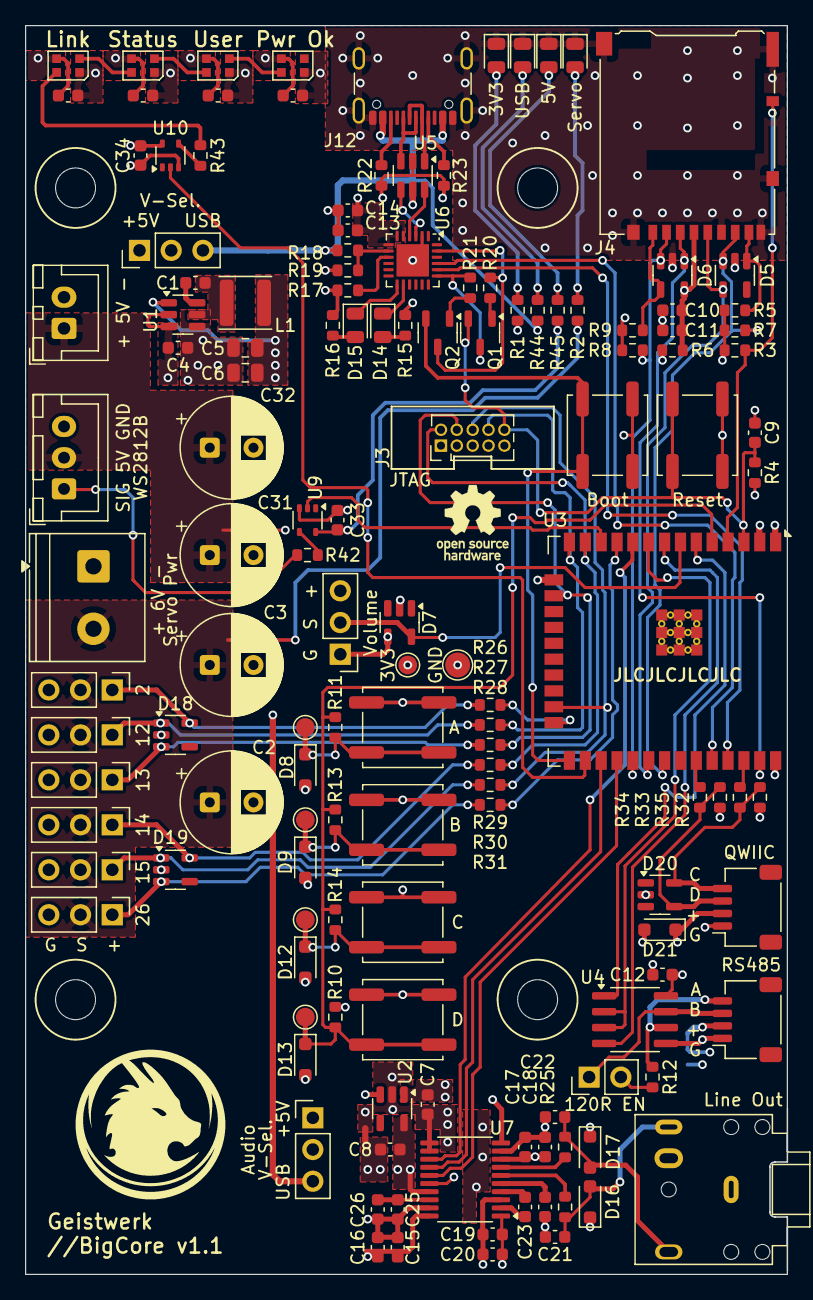
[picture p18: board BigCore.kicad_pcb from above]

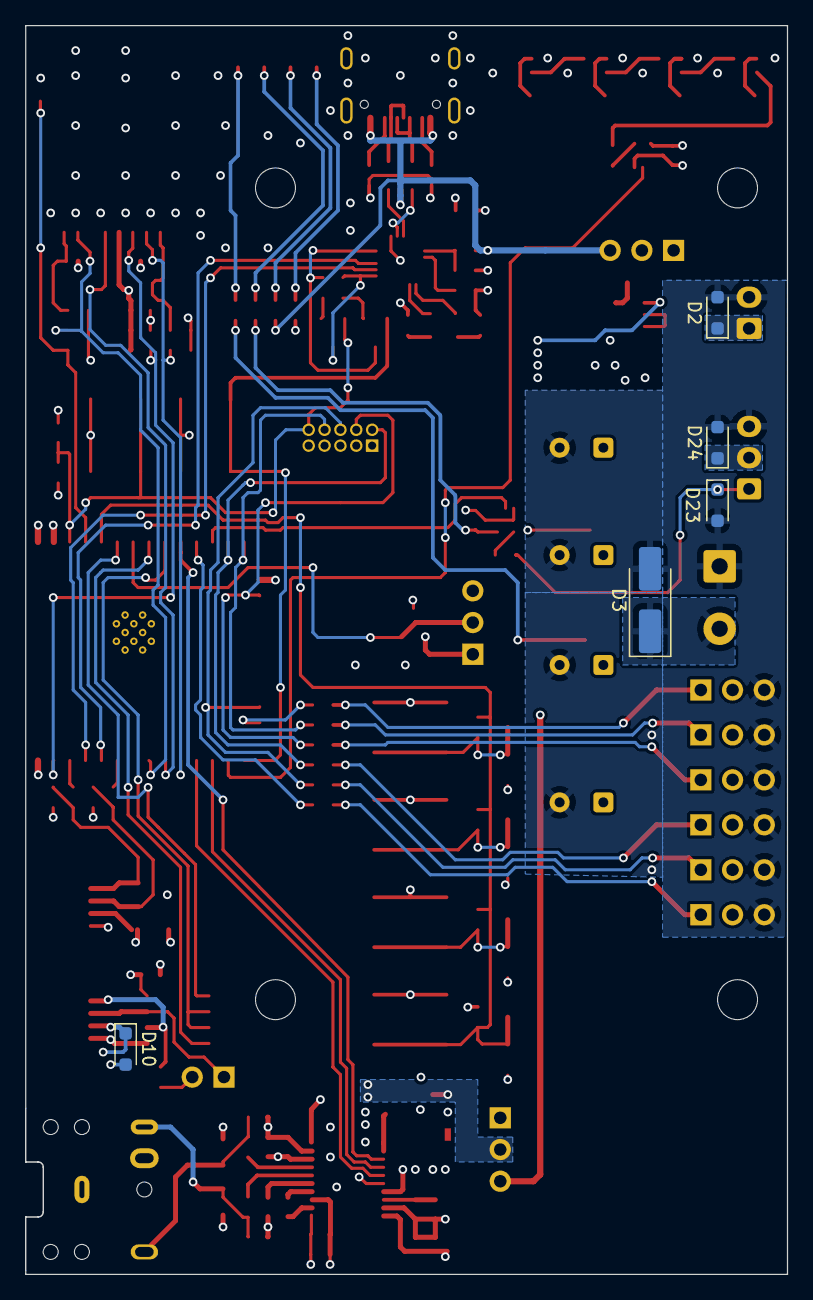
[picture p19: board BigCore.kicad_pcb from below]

Board: 4 copper layers, 61.0 x 100.0 mm, 150 parts (5 on the bottom side), 89 nets.

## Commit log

2025-09-04 - I2C entfernt - Logo hinzugefügt - Spannungsauswahl für Audio (USB oder +5V) hinzugefügt - Spannung für WS2812 LEDs ändert sich jetzt zusammen mit +5VD Auswahl
    [BigCore.kicad_pcb, i2c.kicad_sch, powersupply.kicad_sch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]
2025-09-05 Changed the WS2812 driver IC Optimized the Analog GND and AVCC routing Changed RS485 driver Removed TVS Diode at the RS485 driver (already has 15kV rating)
    [BigCore.kicad_pcb, BigCore.kicad_sch, controller.kicad_sch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]
2025-09-08 Changed Line Out Connector
    Changed Line Out Connector
    [BigCore.kicad_pcb, BigCore.kicad_sch, audio.kicad_sch]
2025-09-13 Footprint changes
    Changed WS2812 from 5050 to 2020
    Changed ESP32 to correct revision
    [BigCore.kicad_pcb, controller.kicad_sch, powersupply.kicad_sch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]
2025-09-14 First Manufactured Version
    A few silkscreen changes
    [BigCore.kicad_pcb, BigCore.kicad_sch, powersupply.kicad_sch]
2025-09-27 SD-Card Fix
    - DAT0 and DAT1 where flipped
    - Changed footprint for ESD-Diodes D16 and D17 to be more hand-soldering friendly
    [BigCore.kicad_pcb]
2025-09-27 Silkscreen fix
    Fixed wrong silkcreen text for the DAC Voltage-Source. USB and +5V are flipped
    [BigCore.kicad_pcb, BigCore.kicad_sch, audio.kicad_sch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]
2025-10-05 PCB Version Bump
    -Bumped PCB to Version 1.1
    [BigCore.kicad_pcb]
2025-10-05 Added schematic as pdf
2025-10-06 Renamed PCB
    [BigCore.kicad_pcb]
2025-10-11 Refreshed the BOM
    [BigCore.csv, BigCore.kicad_pcb, BusServos.kicad_sch]
